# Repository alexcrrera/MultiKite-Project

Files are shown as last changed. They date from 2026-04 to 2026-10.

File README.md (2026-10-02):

# MULTIKITE PROJECT
Lausanne, Switzerland | 2026

Co-developed the take-off and landing mechanism for a multi-kite wind-energy prototype with another student.

Automated take-off and landing sequences using an Arduino-based controller and operator interface, replacing manual actuation with high-level commands to reduce operator intervention and support safer, repeatable operation.

<p align="center">
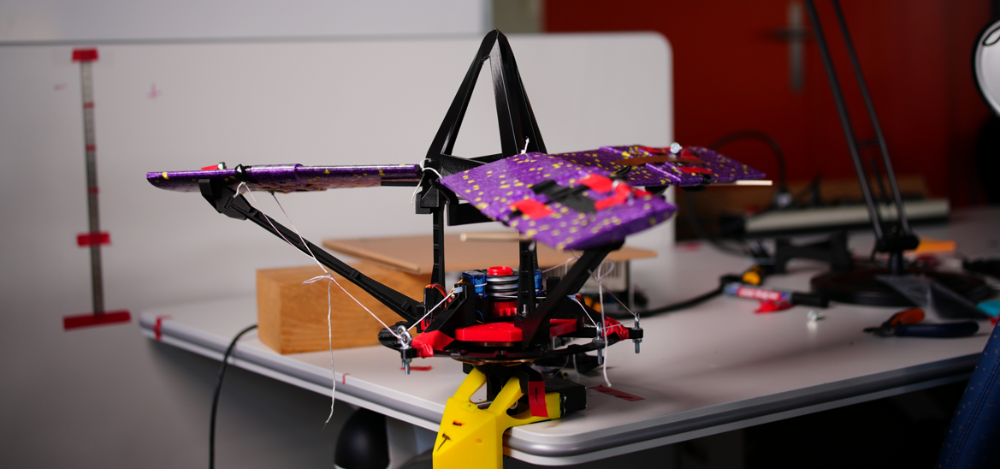
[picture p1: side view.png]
  
</p>

<p align="center">
  <i>Assembly</i>
</p>

<p align="center">
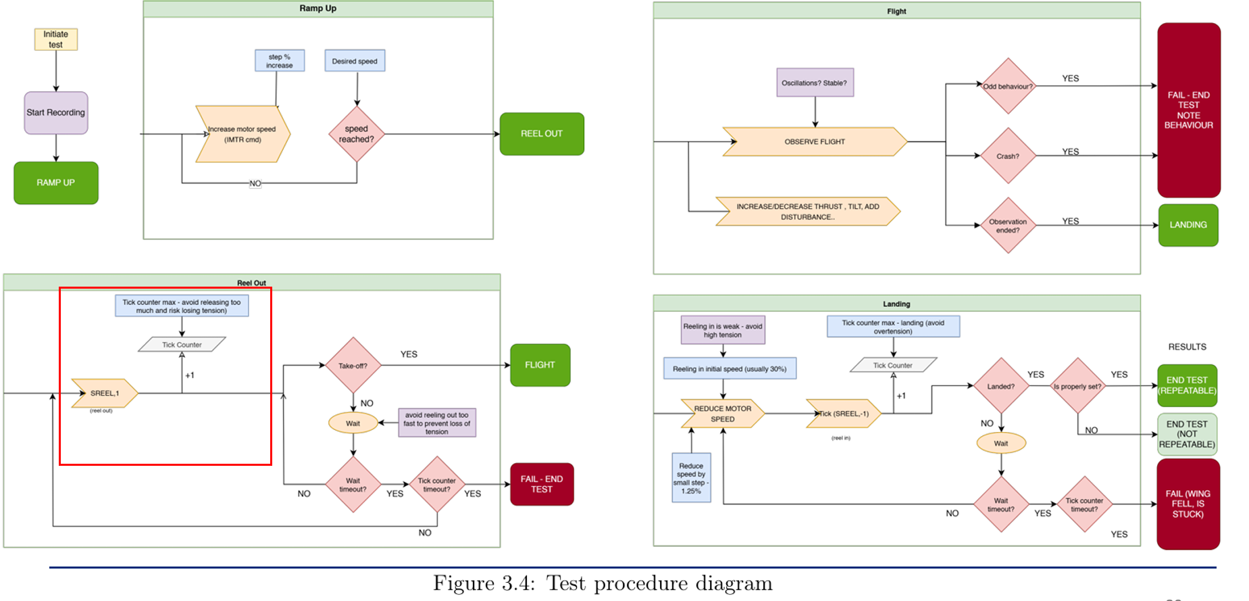
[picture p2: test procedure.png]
  
</p>

Ground station setup guide: how to upload the firmware to an Arduino Mega and connect it to Serial Studio for live telemetry and control.

The following is a detailed step-by-step tutorial for reproductability:

---

## Table of Contents

1. [Hardware Required](#1-hardware-required)
2. [Wiring](#2-wiring)
3. [Install Arduino IDE](#3-install-arduino-ide)
4. [Install Required Libraries](#4-install-required-libraries)
5. [Upload the Sketch](#5-upload-the-sketch)
6. [Install Serial Studio](#6-install-serial-studio)
7. [Configure and Connect Serial Studio](#7-configure-and-connect-serial-studio)
8. [Verify the Connection](#8-verify-the-connection)
9. [Command Reference](#9-command-reference)

---

## 1. Hardware Required

| Item | Notes |
|---|---|
| Arduino Mega 2560 | Any genuine or compatible board |
| Hobbywing ESC | Pulse range 850–1940 µs; other ESCs may need `b_systemParameters.ino` adjusted |
| Base tilt servo | Continuous rotation or position servo (see wiring note) |
| Reel servo | Continuous rotation servo |
| USB Type-B cable | USB-A to USB-B, used for programming and serial communication |
| External 5 V BEC or power supply | For servo power — do **not** power servos from the Arduino 5 V pin |

---

## 2. Wiring

The three actuators connect to PWM-capable pins on the Mega. All signal wires share a common ground with the Arduino.

```
                  Arduino Mega 2560
                 ┌─────────────────────┐
  Base Tilt ◄── │ Pin  9  (PWM / OC2B)│
  ESC       ◄── │ Pin 10  (PWM / OC2A)│
  Reel      ◄── │ Pin 11  (PWM / OC1A)│
                │                     │
  GND rail  ◄── │ GND                 │
  PC        ◄── │ USB (programming    │
                │      + telemetry)   │
                └─────────────────────┘
```

**Servo power**: connect signal and ground from the Arduino; power the servo rail from an external BEC. Never run servo power through the Arduino's 5 V regulator — stall current can exceed its rating and damage the board.

**Changing pin assignments**: edit `BASE_PIN`, `ESC_PIN`, and `REEL_PIN` in `b_systemParameters.ino`. Verify the replacement pins support hardware PWM on the Mega — not all digital pins do.

---

## 3. Install Arduino IDE

### Windows

1. Download Arduino IDE 2.x from [arduino.cc/en/software](https://www.arduino.cc/en/software).
2. Run the `.exe` installer and accept the defaults (includes USB drivers for the Mega).
3. Launch Arduino IDE.

### macOS

1. Download the `.dmg` from [arduino.cc/en/software](https://www.arduino.cc/en/software).
2. Open the disk image and drag **Arduino IDE** into **Applications**.
3. On first launch, macOS may prompt to install additional components — allow it.

### Linux (Ubuntu / Debian)

```bash
# Option A – AppImage (recommended, always up to date)
chmod +x arduino-ide_*.AppImage
./arduino-ide_*.AppImage

# Option B – apt (may install an older version)
sudo apt update && sudo apt install arduino
```

---

## 4. Install Required Libraries

The sketch depends on three libraries. Install them via **Tools → Manage Libraries…** in Arduino IDE.

| Library | Search term in Library Manager | Purpose |
|---|---|---|
| **TextParser** | `TextParser` (by Alex Taujenis) | Parses comma-separated incoming commands |
| **elapsedMillis** | `elapsedMillis` | Non-blocking millisecond/microsecond timers |
| **Servo** | Built-in — no install needed | PWM output to ESC and servos |

> **TextParser note**: if the Library Manager search returns no results, install manually:
> 1. Download from [arduinotextparser.readthedocs.io](https://arduinotextparser.readthedocs.io/en/latest/).
> 2. In Arduino IDE: **Sketch → Include Library → Add .ZIP Library…** and select the downloaded file.

---

## 5. Upload the Sketch

### 5.1 Select board and port

1. Connect the Arduino Mega to the computer via USB.
2. In Arduino IDE: **Tools → Board → Arduino AVR Boards → Arduino Mega or Mega 2560**.
3. **Tools → Processor → ATmega2560**.
4. **Tools → Port** — select the port that appeared when you plugged in the Mega:
   - **Windows**: `COMx` (e.g., `COM3`). If unsure: Device Manager → Ports (COM & LPT).
   - **macOS**: `/dev/cu.usbmodem` followed by a number.
   - **Linux**: `/dev/ttyACM0` or `/dev/ttyUSB0`. Run `ls /dev/tty*` before and after plugging in to find the new entry.

### 5.2 Open the sketch

**File → Open** → navigate to `src/mainCodeKite/mainCodeKite.ino`.

Arduino IDE loads all `.ino` files in the folder as tabs automatically. You should see tabs for `a_userParameters`, `b_systemParameters`, `c_parametersCheck`, `e_setupConfiguration`, `g_auxComputing`, `h_motorsUtilities`, `i_telemetryUtilities`, and `z_mainBody`.

### 5.3 Compile and upload

1. Click **Upload** (the right-arrow button) or press **Ctrl+U** (Cmd+U on macOS).
2. The IDE compiles then uploads. Watch the output panel at the bottom.
3. A successful upload ends with: `avrdude done. Thank you.`
4. Open **Tools → Serial Monitor**, set baud rate to **57600**. The board should print `STARTUP COMPLETE` within a second of resetting.

> **Compilation errors**: if the compiler rejects a value in `a_userParameters.ino`, the `static_assert` checks in `c_parametersCheck.ino` will display a descriptive error message. Fix the parameter and re-upload.

---

## 6. Install Serial Studio

Serial Studio is the ground station GUI used to display telemetry and send commands.
Download the latest release from: [github.com/Serial-Studio/Serial-Studio/releases](https://github.com/Serial-Studio/Serial-Studio/releases)

### Windows

1. Download the `.exe` installer.
2. Run it; default install location is fine.
3. Launch **Serial Studio** from the Start Menu.

### macOS

1. Download the `.dmg`.
2. Open it and drag **Serial Studio** to **Applications**.
3. First launch: right-click the app → **Open** to bypass Gatekeeper, then click **Open** in the dialog.

### Linux

1. Download the `.AppImage`.
2. Make it executable and run:
   ```bash
   chmod +x SerialStudio-*.AppImage
   ./SerialStudio-*.AppImage
   ```
3. If FUSE is missing: `sudo apt install libfuse2` then retry.

---

## 7. Configure and Connect Serial Studio

### 7.1 Load the project file

1. Launch Serial Studio.
2. **File → Open Project** (or drag-and-drop) → select:
   ```
   Base Station/base.json
   ```
   This loads the dashboard layout and all pre-configured action buttons.

### 7.2 Set connection parameters

In the left-side connection panel, configure:

| Parameter | Value | Reason |
|---|---|---|
| Port | Same port as in Arduino IDE | Whichever COM/tty the Mega is on |
| Baud Rate | **57600** | Must match `TELEM_BAUDRATE` in `a_userParameters.ino` |
| Data bits | 8 | Arduino default |
| Parity | None | Arduino default |
| Stop bits | 1 | Arduino default |
| Flow control | None | |

### 7.3 Connect

Click **Connect**. Serial Studio begins parsing frames and populates the dashboard.

The dashboard contains two panels:

| Panel | Contents |
|---|---|
| **STATUS** | Position (PX/PY/PZ), orientation (Yaw/Pitch/Roll), error message, acknowledgement message |
| **MOTOR STATUS** | Motor thrust bar, arm/disarm status, mode, brake status |

> Most STATUS fields (position, orientation) are currently commented out in the firmware and will show `--.-` until sensors are wired and those code sections are enabled.

---

## 8. Verify the Connection

After clicking Connect you should see:

- **ACK Message** field: `STARTUP COMPLETE` (sent once at boot), then `NO ERRORS` cycling at 10 Hz.
- **MOTOR STATUS**: `DISARMED`.
- **MOTOR THRUST**: `0` (bar at zero).

If all fields show `--.-`:
1. Confirm baud rate is `57600` on both the Arduino and Serial Studio.
2. Confirm the correct port is selected (not a Bluetooth COM port or another device).
3. Re-open the project JSON file in Serial Studio — the frame parser may need to reload.
4. Try pressing the Mega's reset button; it re-sends `STARTUP COMPLETE`.

---

## 9. Command Reference

These are the action buttons pre-configured in the Serial Studio project file. Buttons send commands over the same serial port used for telemetry.

| Button label | Command sent | Effect on firmware |
|---|---|---|
| ARM MOTOR | `MARM` | Sets `motor_armed = true` |
| DISARM MOTOR | `DSRM` | Sets `motor_armed = false` |
| MOTOR ON/OFF | `MTEST` | Toggles test mode — motor must be armed first |
| THR+ | `IMTR,2.5` | Adds 2.5 % to `motor_test_percentage` (clamped to `MOTOR_MAX_PERCENTAGE`) |
| THR- | `IMTR,-2.5` | Subtracts 2.5 % (clamped to `MOTOR_MIN_PERCENTAGE`) |
| THR+ FINE | `IMTR,1.25` | Adds 1.25 % |
| THR- FINE | `IMTR,-1.25` | Subtracts 1.25 % |
| TILT+ | `SBASE,1` | Starts one tilt-up burst (`BASE_TILT_BURST_TIME_MILLIS` ms) |
| TILT- | `SBASE,-1` | Starts one tilt-down burst |
| REEL IN | `SREEL,-1` | Reels in for one burst (`REEL_BURST_TIME_MILLIS` ms) |
| REEL OUT | `SREEL,1` | Reels out for one burst |

**Motor test procedure** (minimum safe sequence):

```
1. ARM MOTOR        → status changes to ARMED
2. MOTOR ON/OFF     → test mode starts, thrust at MOTOR_MIN_PERCENTAGE (8 %)
3. THR+             → increases by 2.5 % per press (THR+ FINE for 1.25 % steps)
4. MOTOR ON/OFF     → toggles test mode off, motor stops
5. DISARM MOTOR     → returns to safe DISARMED state
```

> For a detailed explanation of the firmware internals, parameter tuning, and how to extend the code, see [docs/CODE_INTERNALS.md](docs/CODE_INTERNALS.md).

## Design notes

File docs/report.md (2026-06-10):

# Automatic Take-Off/Landing Strategies and Control for a Multi-Kite Airborne Wind Energy System

## 1. Introduction

### 1.1 Airborne Wind Energy Systems

- Overview of Airborne Wind Energy (AWE).
- Motivation for replacing conventional wind turbines.
- Introduction to the MultiKite concept.
- Industrial constraints and scalability considerations.

### 1.2 Take-Off and Landing Challenge

- Importance of reliable take-off and landing (TOL) procedures.
- Existing desktop prototype and previous work.
- Limitations of the original high-speed spin-up approach.
- Need for a safer and more repeatable solution.

### 1.3 Objectives

The objectives of this project were:

- Develop a controlled take-off and landing strategy.
- Improve repeatability and operational robustness.
- Understand the critical parameters governing successful flight.
- Generate design recommendations for future prototypes.
- Contribute to the development of an automated TOL procedure.

---

# 2. System Description

### 2.1 Multi-Kite System Overview

- General operating principle.
- Flying wings.
- Cross-kite tether arrangement.
- Ground station and rotation mechanism.

### 2.2 Existing Prototype

- Description of the inherited system.
- Observed flight behavior.
- Previously used take-off procedure.

### 2.3 Design Requirements

Requirements identified at the start of the project:

- Repeatable take-off.
- Repeatable landing.
- Safety.
- Ease of testing.
- Compatibility with future automation.

---

# 3. Development of the Take-Off and Landing Structure

### 3.1 Initial Concepts

- Analysis of Version 0.
- Funnel-based guidance concept.
- Wing support philosophy.
- Preliminary experiments.

### 3.2 Mechanical Design

#### 3.2.1 Structural Extensions

- Radial extension.
- Vertical extension.
- Design rationale.

#### 3.2.2 Wing Support Mechanism

- Funnel geometry.
- Contact points.
- Attachment strategy.

#### 3.2.3 Arm Design

Design requirements:

- Low mass.
- High stiffness.
- Limited elongation.
- Ease of manufacturing.

Final design:

- Parametric geometry.
- Lightweight structure.
- Resistance to oscillatory loads.

### 3.3 Electronics and Software Integration

#### User Interface

- Real-time monitoring.
- Quick actions.
- Logging functionality.
- Safety features.

#### System Integration

- Ground station integration.
- Testing workflow.
- Repeatability improvements.

---

# 4. Experimental Methodology

### 4.1 Test Environment

- Test location.
- Experimental setup.
- Operating conditions.

### 4.2 Performance Metrics

Metrics used to evaluate performance:

- Successful take-off.
- Stable flight.
- Successful landing.
- Repeatability.
- Ease of operation.

### 4.3 Experimental Procedure

#### Pre-Flight Preparation

- Wing inspection.
- Mass balancing.
- Tether adjustment.
- Structural verification.

#### Take-Off Procedure

- Wing positioning.
- Initial rotation.
- Progressive reel-out.
- Transition to flight.

#### Landing Procedure

- Controlled reel-in.
- Wing capture.
- System shutdown.

---

# 5. Experimental Results

### 5.1 Iterative Development Process

The system was developed through successive iterations involving:

- Structural modifications.
- Wing balancing.
- Tether length adjustments.
- Attachment point optimization.

### 5.2 Successful Flight Campaign

#### Stable Take-Off

A controlled take-off procedure was successfully demonstrated by:

1. Holding the wings in a predefined configuration.
2. Initiating rotation.
3. Gradually reeling out the tethers.
4. Allowing aerodynamic forces to progressively establish flight.

#### Stable Flight

- Multiple successful flights were achieved.
- Flight was repeatable under the identified configuration.
- Stable rotational behavior was observed.

#### Landing

- Controlled landings were successfully demonstrated.
- The support structure enabled reliable wing capture.

### 5.3 Operational Procedure

A robust operational procedure was established, covering:

- Pre-flight preparation.
- Take-off sequence.
- Flight monitoring.
- Landing sequence.

This procedure significantly improved consistency compared to the previous direct spin-up method.

---

# 6. Sensitivity Analysis and Failure Investigation

### 6.1 Loss of Repeatability

Following a modification of the experimental setup, the previously successful configuration could not be recovered despite extensive measurements and reconstruction efforts.

### 6.2 Critical Parameters Identified

The experiments revealed strong sensitivity to:

- Wing mass distribution.
- Tether lengths.
- Tether attachment positions.
- Wing resting angle.
- Structural alignment.
- Contact conditions within the support structure.
- Small aerodynamic asymmetries.

### 6.3 Observed Failure Modes

Typical failure modes included:

- Failure to lift off.
- Asymmetric take-off.
- Excessive oscillations.
- Premature contact with the structure.
- Unstable flight behavior.

### 6.4 Lessons Learned

A major outcome of this work is the identification of the extreme sensitivity of the take-off phase.

Small variations in geometry or mass distribution can significantly affect system behavior and determine whether take-off succeeds or fails.

This finding highlights the need for:

- Tight manufacturing tolerances.
- Precise assembly procedures.
- Calibration methodologies.
- Improved robustness in future designs.

---

# 7. Discussion

### 7.1 Advantages of the Proposed Approach

Compared to the previous high-speed spin-up method:

- Lower required rotational speeds.
- Improved control during take-off.
- Cleaner landing procedure.
- Better suitability for automation.

### 7.2 Current Limitations

The developed structure presents several drawbacks:

#### Radial Structural Extension

- Increased inertia.
- Increased hazard during operation.

#### Vertical Structural Extension

- Additional mass.
- Increased overall dimensions.

#### General Limitations

- Large footprint.
- Complex assembly.
- Strong parameter sensitivity.

### 7.3 Implications for Future Systems

The results suggest that future designs should prioritize:

- Mechanical simplicity.
- Reduced sensitivity.
- Automated calibration.
- Reduced structural mass.

---

# 8. Next-Generation Take-Off Structure

### 8.1 Motivation

The current structure successfully demonstrated the concept but remains too large and complex for future development.

### 8.2 Proposed Concept

Potential improvements include:

- Retractable support arms.
- Hook-based retention mechanism.
- Passive deployment through centrifugal force.
- Integrated damping mechanisms.

### 8.3 Expected Benefits

Compared to the current version:

- Reduced mass.
- Reduced inertia.
- Smaller storage volume.
- Lower aerodynamic interference.
- Simplified operation.

### 8.4 Future Work

Future efforts should focus on:

- Validation of the new concept.
- Reduction of parameter sensitivity.
- Development of automatic take-off procedures.
- Development of automatic landing procedures.
- Integration with flight control systems.

---

# 9. Conclusion

This project investigated alternative take-off and landing strategies for a MultiKite Airborne Wind Energy system.

A dedicated support structure was designed, constructed, and experimentally validated. Using this structure, repeatable take-off, stable flight, and controlled landing were successfully demonstrated.

The experimental campaign revealed that the system is highly sensitive to small geometric and mass-property variations. While this sensitivity ultimately prevented recovery of the original successful configuration after modifications, it provided valuable insight into the dominant factors governing take-off behavior.

The limitations identified in the current architecture motivated the development of a next-generation concept aimed at reducing mass, inertia, complexity, and sensitivity while improving suitability for future automation.

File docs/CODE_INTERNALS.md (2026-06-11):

# MultiKite Firmware Internals

Reference for anyone modifying the Arduino sketch. Assumes familiarity with embedded C++, PWM, and serial protocols. Does not re-explain Arduino basics.

---

## Table of Contents

1. [File Structure](#1-file-structure)
2. [Execution Flow](#2-execution-flow)
3. [Serial Protocol](#3-serial-protocol)
   - [Outgoing telemetry](#31-outgoing-telemetry)
   - [Incoming commands](#32-incoming-commands)
4. [Actuator Subsystems](#4-actuator-subsystems)
   - [ESC / Motor](#41-esc--motor-pin-10)
   - [Reel Servo](#42-reel-servo-pin-11)
   - [Base Tilt Servo](#43-base-tilt-servo-pin-9)
   - [Burst timing logic](#44-burst-timing-logic)
5. [Motor State Machine](#5-motor-state-machine)
6. [Parameter Reference](#6-parameter-reference)
7. [How to Extend](#7-how-to-extend)
   - [Add a telemetry field](#71-add-a-telemetry-field)
   - [Add an incoming command](#72-add-an-incoming-command)
   - [Adjust timing and speed](#73-adjust-timing-and-speed)
8. [Known Issues and Discrepancies](#8-known-issues-and-discrepancies)

---

## 1. File Structure

Arduino compiles all `.ino` files in the sketch folder into a single translation unit, concatenated alphabetically by filename. The naming convention (`a_`, `b_`, ..., `z_`) enforces a deliberate include order.

| File | Compile order | Role |
|---|---|---|
| `mainCodeKite.ino` | 1 (main tab) | Comment header only; no code |
| `a_userParameters.ino` | 2 | All user-tunable `constexpr` values — **the only file end-users should edit** |
| `b_systemParameters.ino` | 3 | Hardware pin assignments, object declarations, runtime state variables, pulse ranges — do not modify unless changing hardware |
| `c_parametersCheck.ino` | 4 | `static_assert` guards that reject invalid parameter combinations at compile time |
| `e_setupConfiguration.ino` | 5 | `initSystem()`, `initServos()`, `initTelem()` called once from `setup()` |
| `g_auxComputing.ino` | 6 | State validation (`checkStateSystem()`), EWA filter, utility math |
| `h_motorsUtilities.ino` | 7 | Periodic handlers (`handleMotor()` etc.) and low-level PWM write functions |
| `i_telemetryUtilities.ino` | 8 | Serial read/write, frame parser, command dispatch (`processTelem()`) |
| `z_mainBody.ino` | 9 (last) | `setup()` and `loop()` entry points |

> `z_mainBody.ino` is last so all declarations in earlier files are visible. Do not move `setup()`/`loop()` to another file.

---

## 2. Execution Flow

`setup()` runs once; `loop()` runs continuously.

```mermaid
flowchart TD
    A([Power on / Reset]) --> B[setup]
    B --> B1["Serial.begin(57600)"]
    B1 --> B2[initSystem]
    B2 --> B3["initTelem() → TELEM.begin(TELEM_BAUDRATE)"]
    B2 --> B4["initServos() → attach + arm ESC + set stop pulses"]
    B2 --> B5["sendMessage('STARTUP COMPLETE')"]
    B5 --> L([loop])

    L --> C[checkStateSystem]
    C --> D[handleTelemetry]
    D --> D1{"micros() interval\n= 1e6 / TELEMETRY_FREQUENCY"}
    D1 -->|elapsed| D2[sendTelem]
    D1 -->|not yet| D3[readTelem / processTelem]
    D2 --> D3

    D3 --> E[handleReelServo]
    E --> E1{"millis() interval\n= 1000 / REEL_SERVO_FREQUENCY"}
    E1 -->|elapsed| E2[reelServoWrite]
    E1 -->|not yet| F[handleMotor]
    E2 --> F

    F --> F1{"millis() interval\n= 1000 / MOTOR_FREQUENCY"}
    F1 -->|elapsed| F2[motorWrite]
    F1 -->|not yet| G[handleBaseTiltServo]
    F2 --> G

    G --> G1{"millis() interval\n= 1000 / BASE_TILT_SERVO_FREQUENCY"}
    G1 -->|elapsed| G2[baseTiltServoWrite]
    G1 -->|not yet| L
    G2 --> L
```

**Timing model**: all scheduling uses software polling (`millis()`/`micros()` deltas stored in `static` local variables). There are no hardware interrupts or RTOS tasks. The loop is cooperative; a blocking call in any handler will delay all others. Keep all handlers fast — no `delay()` after `setup()`.

---

## 3. Serial Protocol

A single hardware `Serial` port (USB) carries both outgoing telemetry and incoming commands, bidirectionally, at the same baud rate.

### 3.1 Outgoing Telemetry

**Direction**: Arduino → PC (Serial Studio)  
**Rate**: `TELEMETRY_FREQUENCY` Hz (default 10 Hz)  
**Framing**: newline before, `*` after each packet

```
\n$MKTE,f1,f2,f3,...,f27*
```

`sendTelem()` builds a `String fields[28]` array and serialises it. Fields not assigned default to an empty string, appearing as empty between consecutive commas.

**Active field map** (indices that currently carry data):

| Index | Variable | Type | Example value |
|---|---|---|---|
| 0 | Frame header | literal | `$MKTE` |
| 10 | `motor_output_percentage` | float | `23.5` |
| 11 | `motor_on` | string | `ON` / `OFF` |
| 12 | `motor_armed` | string | `ARMED` / `DISARMED` |
| 17 | Flight mode | string | `TEST MODE` / `STANDBY` |
| 25 | `errorMessage` | string | `NO ERRORS` |
| 26 | `returnMessage` | string | `MOTOR ARMED` |
| 27 | Fixed checksum stub | literal | `12` |

All other indices (1–9, 13–16, 18–24) are reserved for future sensors (IMU, GPS, SD card status) and are commented out in `i_telemetryUtilities.ino`.

**Example packet** (most fields empty):

```
\n$MKTE,,,,,,,,,,,23.50,ON,ARMED,,,,, STANDBY,,,,,,,,,,NO ERRORS,MOTOR ARMED,12*
```

**Adding more fields**: see [§7.1](#71-add-a-telemetry-field).

---

### 3.2 Incoming Commands

**Direction**: PC (Serial Studio) → Arduino  
**Framing**: newline-terminated (`\n` is the end-of-line delimiter in Serial Studio actions)

`readTelem()` reads one character at a time into a 50-byte circular buffer (`incomingDataTelem`). On receiving `\n`, it copies the buffer to `incomingDataTelemString` and calls `processTelem()`.

`processTelem()` calls `checkHeaderTelem()` first, which does substring matching (`indexOf`) against known command strings and sets a `TelemIdentity` integer used in the `switch` dispatch.

```mermaid
flowchart TD
    A[character received on TELEM] --> B{char == newline?}
    B -->|yes| C[copy buffer to incomingDataTelemString]
    B -->|no| D{buffer overflow?\nindex >= 49}
    D -->|yes| E[reset index and string]
    D -->|no| F[append char, increment index]
    C --> G[processTelem]
    G --> H[checkHeaderTelem]
    H --> I{TelemIdentity}
    I -->|-1 no match| Z[return]
    I -->|14 IMTR| J["commaParser.parseLine → adjust motor_test_percentage"]
    I -->|15 SBASE| K[set base_tilt_down or base_tilt_up + record burst start]
    I -->|16 SREEL| L[set reel_in or reel_out + record burst start]
```

**Command table**:

| Keyword detected | `TelemIdentity` | Expected format | Action |
|---|---|---|---|
| `MARM` | (direct) | `MARM` | `motor_armed = true` |
| `DSRM` | (direct) | `DSRM` | `motor_armed = false` |
| `MOFF` | (direct) | `MOFF` | `motor_on = false` |
| `MTEST` | (direct) | `MTEST` | `toggleTest()` |
| `IMTR` | 14 | `IMTR,<float>` | `motor_test_percentage += inter`, clamped |
| `SBASE` | 15 | `SBASE,<-1\|1>` | Sets tilt direction flag + burst timer |
| `SREEL` | 16 | `SREEL,<-1\|1>` | Sets reel direction flag + burst timer |
| `TAO` | (direct) | `TAO` | Placeholder; sets `returnMessage` only |
| `LND` | (direct) | `LND` | Placeholder; sets `returnMessage` only |

**`checkHeaderTelem` evaluation order**: commands are checked via sequential `if` blocks, not `else if`. Multiple keywords in the same packet will all match. In practice Serial Studio sends one command per button press, so this is not a concern. Be aware when sending raw commands manually.

**`commaParser`** (TextParser library) is used only for the two-field commands (`IMTR`, `SBASE`, `SREEL`). It parses `COMMAND,VALUE` and returns the float value in `inter`.

---

## 4. Actuator Subsystems

All three actuators are controlled via the Arduino `Servo` library which outputs 50 Hz PWM with microsecond-precision pulse width. The ESC interprets this signal identically to a standard RC receiver.

### 4.1 ESC / Motor (Pin 10)

| Parameter | Value | Source |
|---|---|---|
| Pulse range | 850–1940 µs | Hobbywing datasheet |
| Update rate | 50 Hz (20 ms) | `MOTOR_FREQUENCY` |
| 0 % → pulse | 850 µs | `ESC_LOW_PULSE` |
| 100 % → pulse | 1940 µs | `ESC_HIGH_PULSE` |
| Max user-settable | 50 % → ~1395 µs | `MOTOR_MAX_PERCENTAGE` |
| Min user-settable | 8 % → ~941 µs | `MOTOR_MIN_PERCENTAGE` |

`motorWrite()` maps `motor_output_percentage` linearly onto the pulse range using `map()`. If `motor_on` or `motor_armed` is false, `motor_output_percentage` is forced to 0 and the ESC receives `ESC_LOW_PULSE` (idle/brake signal).

**ESC arming sequence**: `initServos()` writes `ESC_LOW_PULSE` and calls `delay(1000)` — this 1-second low pulse at startup is required by most ESCs to complete their arming handshake. Do not remove this delay.

---

### 4.2 Reel Servo (Pin 11)

The reel servo is a continuous rotation servo commanded by pulse width. The midpoint pulse (`REEL_STOP_PULSE = 1500 µs`) means stopped. Pulses above stop spin in one direction; pulses below spin in the other.

| Parameter | Value |
|---|---|
| Pulse range | 1000–2000 µs |
| Stop pulse | 1500 µs (midpoint) |
| Update rate | 50 Hz |
| Reel-in speed | `REEL_STOP_PULSE × (1 − REEL_SPEED_DELTA_PERCENTAGE_REEL_IN)` |
| Reel-out speed | `REEL_STOP_PULSE × (1 + REEL_SPEED_DELTA_PERCENTAGE_REEL_OUT)` |
| Burst duration | `REEL_BURST_TIME_MILLIS` ms |

Speed is controlled by a fractional offset from the stop pulse. `REEL_SPEED_DELTA_PERCENTAGE_REEL_IN = 0.08` means reel-in pulse = `1500 × 0.92 = 1380 µs`.

---

### 4.3 Base Tilt Servo (Pin 9)

Identical architecture to the reel servo. The pulse range is asymmetric (1000–1940 µs), so the stop pulse is slightly off-centre:

```
BASE_TILT_STOP_PULSE = round((1000 + 1940) / 2.0) = 1470 µs
```

Speed offsets are applied relative to `BASE_TILT_STOP_PULSE`:

```
tilt-down pulse = STOP + DELTA_POSITIVE × (HIGH − STOP)
                = 1470 + 0.2 × (1940 − 1470)
                = 1470 + 94 = 1564 µs

tilt-up pulse   = STOP − DELTA_NEGATIVE × (STOP − LOW)
                = 1470 − 0.2 × (1470 − 1000)
                = 1470 − 94 = 1376 µs
```

The naming convention ("positive tilt" = `base_tilt_down`) follows the mechanical geometry of the specific platform; verify direction on your hardware before flying.

---

### 4.4 Burst Timing Logic

Reel and base tilt both use a burst model: a single command fires the servo for a fixed duration, then it returns to stop automatically. This prevents runaway actuation from dropped commands.

```mermaid
flowchart TD
    A[SREEL or SBASE command received] --> B[set direction flag = true\nrecord burst_start_time = millis]
    B --> C([next handleXServo tick])
    C --> D{"millis() − burst_start_time\n>= BURST_TIME?"}
    D -->|no| E["write direction pulse\n(reel-in / reel-out / tilt-up / tilt-down)"]
    E --> C
    D -->|yes| F[reset direction flags to false\nburst_start_time = 0]
    F --> G[write STOP_PULSE]
    G --> C
```

**Key consequence**: the "STOP TILTING" button (`SBASE,0`) sends a value of 0, which falls through the `processTelem()` switch without matching any case. The servo does **not** stop early — it always runs the full burst duration. If you need a genuine early-abort command, add an explicit `inter == 0` branch that clears the direction flags.

---

## 5. Motor State Machine

Three boolean variables drive motor behaviour: `motor_armed`, `motor_on`, `motor_test_mode`.

```mermaid
stateDiagram-v2
    [*] --> Idle : power-on default

    Idle --> Armed : MARM
    Armed --> Idle : DSRM or MOFF

    Armed --> TestMode : MTEST\n(sets motor_on = true\nmotor_test_percentage = MIN)
    TestMode --> TestMode : IMTR,±x\n(adjusts test_percentage, clamped MIN..MAX)
    TestMode --> Idle : second MTEST\nor MOFF or DSRM

    note right of Idle
        motor_armed = false
        motor_on    = false
        motor output = 0
    end note

    note right of Armed
        motor_armed = true
        motor_on    = false
        motor output = 0
    end note

    note right of TestMode
        motor_armed = true
        motor_on    = true
        motor_test_mode = true
        motor output = test_percentage
    end note
```

`checkStateSystem()` runs each loop iteration as a guard: if `motor_test_mode` is active but the motor becomes unarmed or turned off (e.g., via a concurrent `DSRM`), it cleans up `motor_test_mode` and resets the test percentage to `MOTOR_MIN_PERCENTAGE`.

Normal (non-test) flight with `motor_on = true` and `motor_test_mode = false` is structurally possible but has no current command to set it. `motor_output_percentage` would need to be driven externally (e.g., from a future autonomous controller).

---

## 6. Parameter Reference

All values in `a_userParameters.ino`. `c_parametersCheck.ino` enforces the bounds listed here at compile time.

| Constant | Default | Unit | Min | Max | Effect |
|---|---|---|-----|-----|---|
| `TELEMETRY_FREQUENCY` | 10 | Hz | 1 | 100 | Outgoing packet rate. Scale baud rate proportionally if increased significantly. |
| `TELEM_BAUDRATE` | 57600 | bps | — | — | Must match Serial Studio. Whitelist: 9600, 14400, 19200, 28800, 38400, 57600, 115200, 230400, 250000, 460800, 921600. |
| `MOTOR_MAX_PERCENTAGE` | 50.0 | % | > MIN | 100 | Hard ceiling on thrust commands. |
| `MOTOR_MIN_PERCENTAGE` | 8.0 | % | 0 | < MAX | Lowest commandable thrust (below this the motor typically cannot spin from rest). |
| `REEL_SPEED_DELTA_PERCENTAGE_REEL_IN` | 0.08 | fraction | > 0 | ≤ 0.20 | Speed as fraction of stop-pulse range. Higher = faster reel-in. |
| `REEL_SPEED_DELTA_PERCENTAGE_REEL_OUT` | 0.06 | fraction | > 0 | ≤ 0.20 | Same for reel-out. |
| `REEL_BURST_TIME_MILLIS` | 300 | ms | > 0 | < 500 | Duration of one SREEL command. |
| `BASE_TILT_SPEED_DELTA_PERCENTAGE_POSITIVE_TILT` | 0.2 | fraction | > 0 | ≤ 0.30 | Fraction of half-range added to stop pulse for tilt-down. |
| `BASE_TILT_SPEED_DELTA_PERCENTAGE_NEGATIVE_TILT` | 0.2 | fraction | > 0 | ≤ 0.30 | Fraction subtracted for tilt-up. |
| `BASE_TILT_BURST_TIME_MILLIS` | 400 | ms | > 0 | < 500 | Duration of one SBASE command. |

**System constants** (in `b_systemParameters.ino`, change only with hardware changes):

| Constant | Value | Notes |
|---|---|---|
| `BASE_PIN` | 9 | Must be a PWM pin |
| `ESC_PIN` | 10 | Must be a PWM pin |
| `REEL_PIN` | 11 | Must be a PWM pin |
| `ESC_LOW_PULSE` | 850 µs | Hobbywing minimum — verify against your ESC datasheet |
| `ESC_HIGH_PULSE` | 1940 µs | Hobbywing maximum |
| `BASE_TILT_LOW_PULSE` | 1000 µs | |
| `BASE_TILT_HIGH_PULSE` | 1940 µs | |
| `REEL_LOW_PULSE` | 1000 µs | |
| `REEL_HIGH_PULSE` | 2000 µs | |
| `bufferSize` | 50 | Max incoming packet length in bytes |

---

## 7. How to Extend

### 7.1 Add a telemetry field

1. **Pick an unused index** (0–27) in `sendTelem()`. Indices 1–9, 13–16, 18–24 are currently empty. Avoid index 0 (header) and 27 (checksum stub).

2. **Assign the value** in `sendTelem()`:
   ```cpp
   fields[18] = String(yourVariable, 2); // 2 decimal places
   ```

3. **Add the field in Serial Studio**:
   - Open `Base Station/base.json` in a text editor.
   - In the appropriate `"groups"` → `"datasets"` array, add a new entry:
   ```json
   {
       "index": 18,
       "title": "MY SENSOR",
       "units": "m/s",
       "widget": "",
       "graph": false
   }
   ```
   - Reload the project file in Serial Studio.

4. **Increase `NUM_FIELDS`** if you need more than 28 fields (unlikely without hardware expansion).

> **Index alignment**: the `index` value in the JSON maps directly to the position in the comma-split array, where index 0 is `$MKTE`. There is no offset.

---

### 7.2 Add an incoming command

1. **Choose a unique keyword** (no spaces, no commas). Check that it does not appear as a substring of an existing keyword — `checkHeaderTelem` uses `indexOf`, not exact match.

2. **Detect the keyword** in `checkHeaderTelem()`:
   ```cpp
   if (incomingDataTelemString.indexOf("MYCMD") != -1) {
       TelemIdentity = 20; // pick an unused case number
   }
   ```

3. **Handle the command** in `processTelem()`:
   ```cpp
   case 20:
       // for a simple flag command, no parsing needed:
       myFlag = true;
       returnMessage = "MY CMD RECEIVED";
       break;

   // or, for a parameterised command:
   case 20:
       commaParser.parseLine(incomingDataTelem, headerTelem, inter);
       myValue = constrain(inter, 0.0f, 100.0f);
       returnMessage = "MY VALUE: " + String(myValue);
       break;
   ```

4. **Add a Serial Studio action button** in the JSON `"actions"` array:
   ```json
   {
       "title": "My Command",
       "txData": "MYCMD,42",
       "eol": "\n",
       "icon": "Services"
   }
   ```

---

### 7.3 Adjust timing and speed

**Increase telemetry rate**: raise `TELEMETRY_FREQUENCY` in `a_userParameters.ino`. At 10 Hz with the current 28-field packet (roughly 150 characters), 57600 baud has headroom. At 50 Hz consider raising `TELEM_BAUDRATE` to 115200 and updating Serial Studio accordingly.

**Change servo update rate**: `REEL_SERVO_FREQUENCY`, `BASE_TILT_SERVO_FREQUENCY`, `MOTOR_FREQUENCY` are all in `b_systemParameters.ino`. Standard servos and ESCs expect 50 Hz; digital servos typically accept up to 330 Hz. Changing these values beyond what the hardware supports may cause erratic behaviour.

**Longer burst steps**: increase `REEL_BURST_TIME_MILLIS` or `BASE_TILT_BURST_TIME_MILLIS`. The `static_assert` clamps both to < 500 ms. To allow longer bursts, raise `REEL_BURST_TIME_MILLIS_CLAMPING` or `BASE_BURST_TIME_MILLIS_CLAMPING` in `b_systemParameters.ino` simultaneously.

---

## 8. Known Issues and Discrepancies

### 8.1 Serial Studio JSON vs firmware field indices

The JSON file in `Base Station/` was authored for an earlier field layout. Several mappings are incorrect with the current firmware:

| JSON label | JSON index | Current firmware field at that index | Correct index for this label |
|---|---|---|---|
| MOTOR THRUST (bar) | 11 | `motor_on` → `"ON"/"OFF"` string | Should be 10 (`motor_output_percentage`) |
| MODE | 18 | empty (unassigned) | Should be 17 (`TEST MODE`/`STANDBY`) |
| ERROR MESSAGE | 26 | `returnMessage` (the ACK) | Should be 25 (`errorMessage`) |
| ACK Message | 27 | fixed `"12"` | Should be 26 (`returnMessage`) |

**Impact**: the motor thrust bar will not animate; the MODE field will show nothing; error and ACK messages are swapped. Fix by editing the `index` values in the JSON or by re-assigning the `fields[]` slots in `sendTelem()`.

---

### 8.2 Double `Serial.begin()` on startup

`z_mainBody.ino` calls `Serial.begin(57600)` directly in `setup()`, then `initSystem()` calls `initTelem()` which calls `TELEM.begin(TELEM_BAUDRATE)`. Since `TELEM` is defined as `Serial`, the port is initialised twice. Arduino handles this gracefully (the second call re-initialises with the same rate), but the hardcoded `57600` in `z_mainBody.ino` will not pick up a changed `TELEM_BAUDRATE` from `a_userParameters.ino`. Remove the raw `Serial.begin(57600)` line from `z_mainBody.ino` to ensure only `initTelem()` controls the baud rate.

---

### 8.3 `SBASE,0` stop command is a no-op

The `processTelem()` case 15 handles values `-1` and `1` only. `SBASE,0` is ignored; the "STOP TILTING" button in Serial Studio has no effect. The servo stops naturally when the burst timer expires. To implement a genuine abort, add `else if (inter == 0) { base_tilt_down = false; base_tilt_up = false; }` in case 15.

---

### 8.4 Reel speed formula inconsistency

The reel-in and reel-out pulses are calculated differently from the base tilt servo:

```cpp
// Reel: multiplicative offset from STOP
reel_in:  REEL_STOP_PULSE * (1 - DELTA_IN)
reel_out: REEL_STOP_PULSE * (1 + DELTA_OUT)

// Base tilt: additive offset scaled to half-range
tilt-down: STOP + DELTA × (HIGH - STOP)
tilt-up:   STOP - DELTA × (STOP - LOW)
```

The reel formula makes the speed delta asymmetric because `REEL_STOP_PULSE` differs from the midpoint of the range only when the range is not centred on 1500 µs (currently it is: `(1000+2000)/2 = 1500`). For the reel servo this produces equivalent results. For a servo with an asymmetric range, use the base-tilt formula instead.

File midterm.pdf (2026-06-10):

# Automatic take-off/landing strategies and control for a multi-kite Airborne Wind Energy system

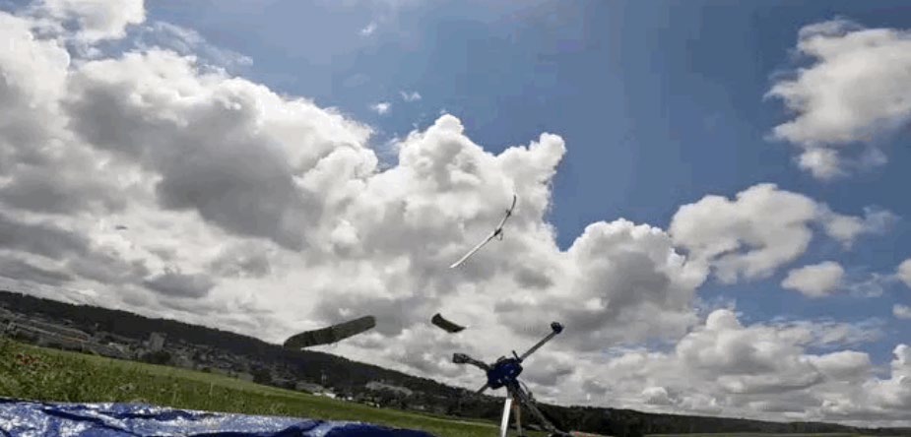
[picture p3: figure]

Alex CARRERA | M1 MT
Midterm Presentation

https://site.alphanemo.com/

Supervision: J. Waibel, Prof. C. Jones

# Context and introduction

https://site.alphanemo.com/

## - Continuation of the work of the AlphAnemo Team - Develop MultiKite Energy Systems - Industrial constraints

# Context and introduction

https://pngtree.com/freepng/png-wind-turbines_14597478.html
- Large structure
- Large cost
- Large footprint (visual)
- Height limits force placement in highly visible areas https://site.alphanemo.com/

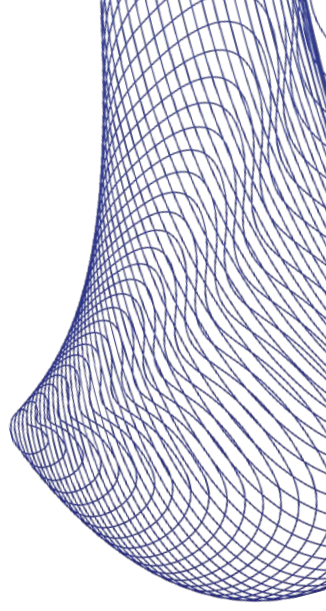
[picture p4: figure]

# Context and introduction

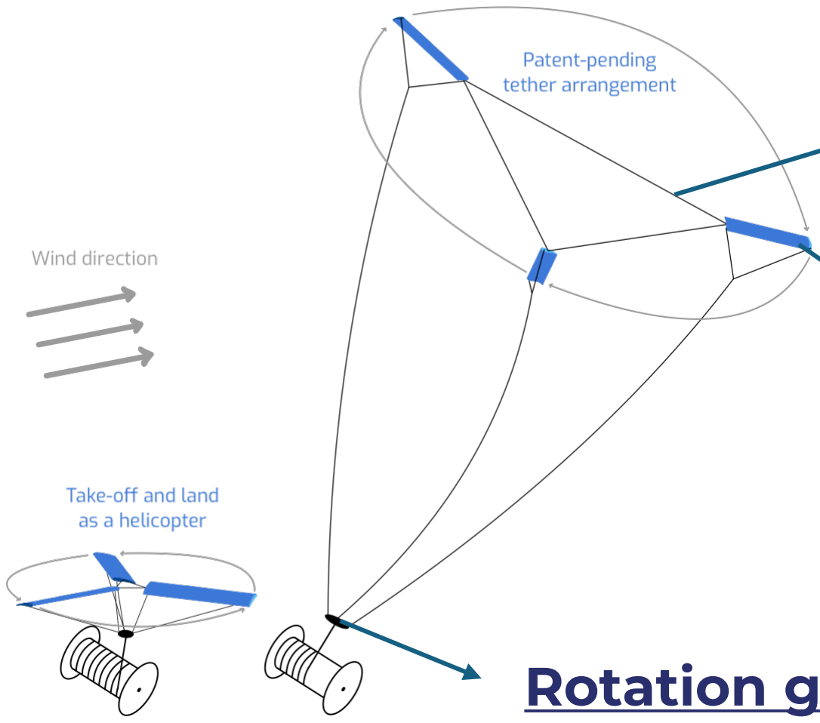
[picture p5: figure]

https://site.alphanemo.com/

Cross-Kite tethers

Rotation generates energy (dynamo)

Flying wings

# Context and introduction

## - Continuation of the work of the AlphAnemo Team

https://site.alphanemo.com/

## - Develop MultiKite Energy Systems - Industrial constraints - Work in pseudo-parallel with another student

# Context and introduction

https://www.linkedin.com/company/alphanemo/post

## - Continuation of the work of the AlphAnemo Team

# Context and introduction

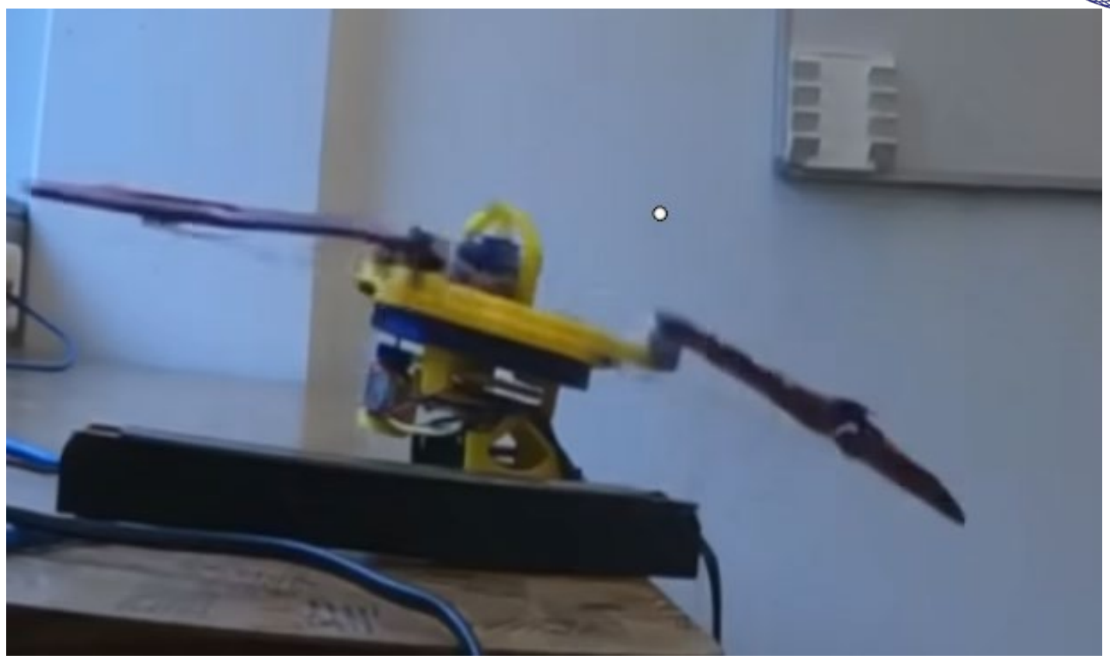
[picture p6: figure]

https://www.linkedin.com/company/alphanemo/post

## - Continuation of the work of the AlphAnemo Team

”chaotic take-off and landing”

# Summary

:

- Context and Introduction Goals First Major Version | Construction | Integration | Testings and results | Limitations and shortcomings Future work and conclusion

# Goals

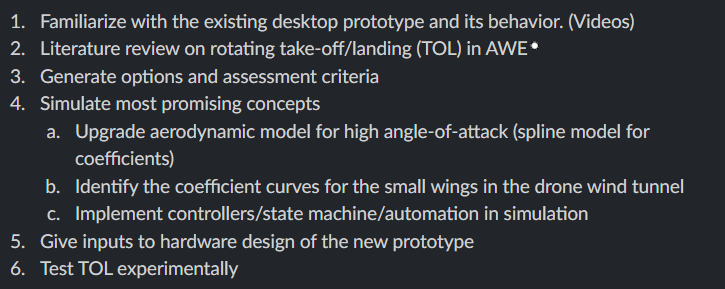
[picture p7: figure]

# Goals

Understand wing configuration

# Goals

# Goals

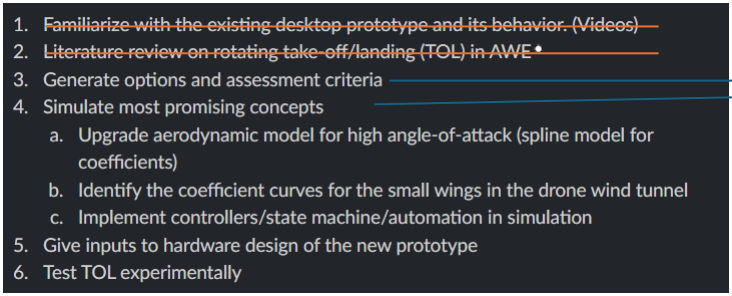
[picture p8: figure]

Version 0 created

# Version 0

funnels

Tether attachement point

30º AOA

# Goals

# Goals

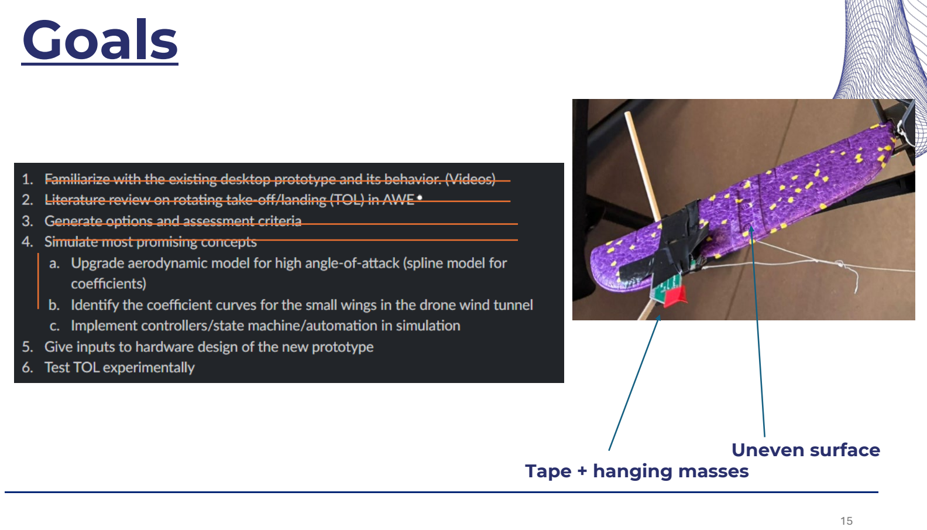
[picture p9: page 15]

Tape + hanging masses

Uneven surface

# Goals

high uncertainty

standby

# Goals

Direct involvement

Current phase (version 1)

# Version 1: Construction and integration

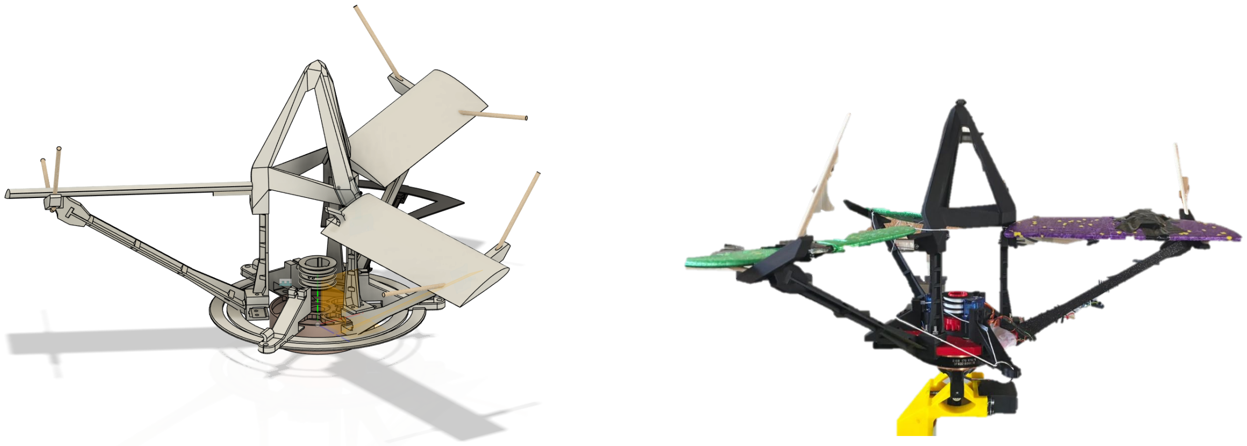
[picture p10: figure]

Projet Image | 18

> Based on Version 0

# Version 1: Construction and integration

Projet Image | 19

> Based on Version 0

# Version 1: Construction and integration

Projet Image | 20

> Based on Version 0

Old desktop prototype | Radial structural extension

Wings supported

Vertical structural extension

# Version 1: Construction and integration

Projet Image | 21

> Based on Version 0

funnel | Contact point

# Version 1: Construction and integration

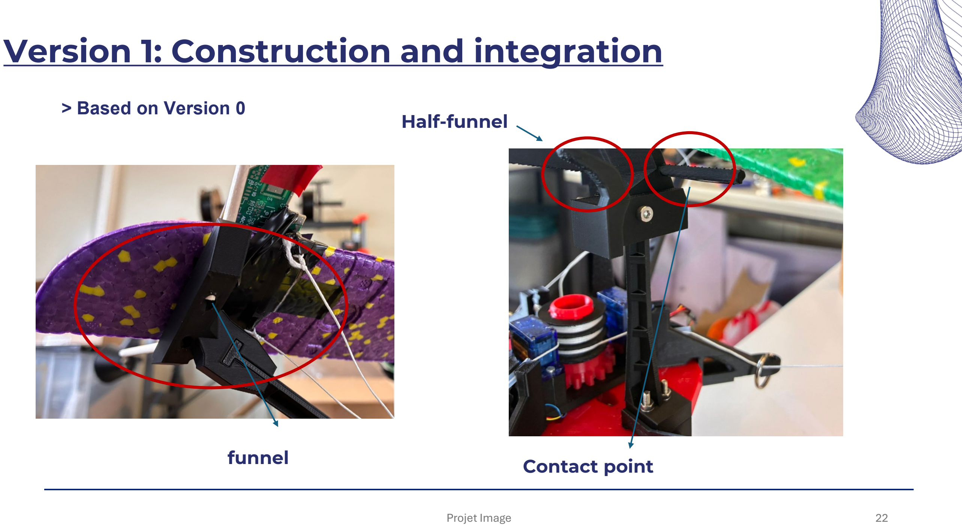
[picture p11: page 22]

Projet Image | 22

> Based on Version 0

funnel | Contact point

Half-funnel

# Version 1: Construction and integration

Projet Image | 23

> Based on Version 0

Contact point

Half-funnel

# Version 1: Construction and integration

Projet Image | 24

> Based on Version 0

“pyramid”

# Version 1: Construction and integration

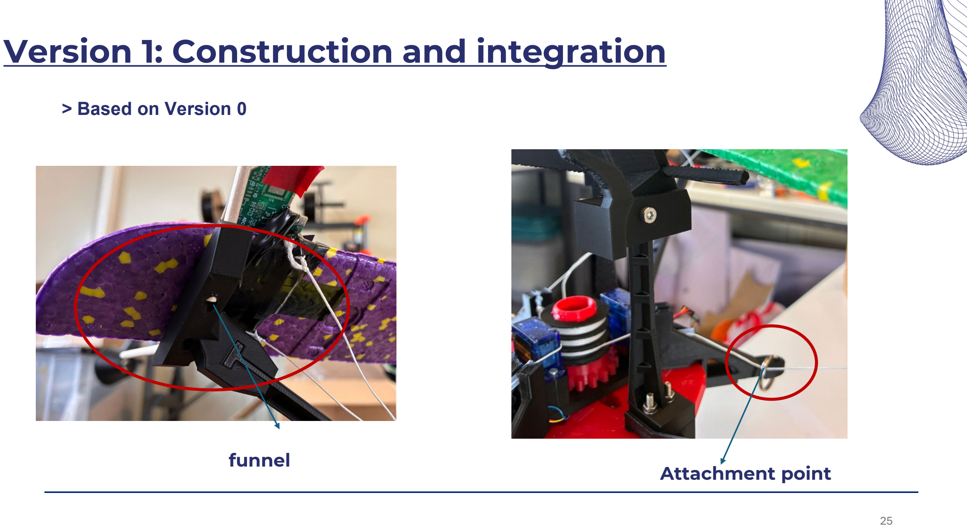
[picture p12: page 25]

> Based on Version 0

funnel | Attachment point

# Version 1

Based on Version 0

Arms:
- Weight requirement
- Strength requirement
- Elongation requirement

# Version 1

Based on Version 0

Arms:
- Weight requirement
- Strength requirement
- Elongation requirement
- > T-shape

# Version 1

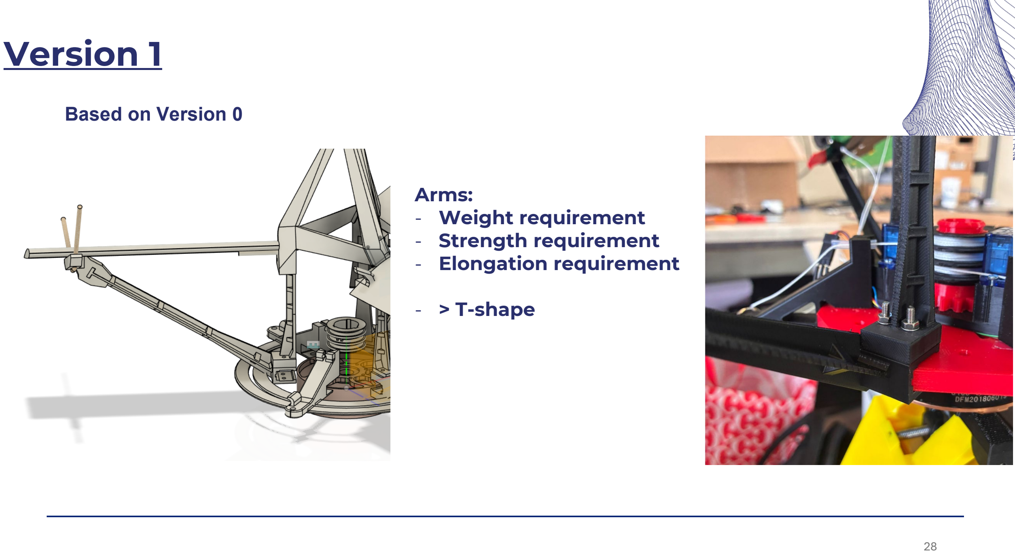
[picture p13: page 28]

Based on Version 0

Arms:
- Weight requirement
- Strength requirement
- Elongation requirement
- > T-shape

# Version 1

Based on Version 0

Arms:
- Weight requirement
- Strength requirement
- Elongation requirement
- > T-shape

# Version 1

Based on Version 0

Arms:
- Weight requirement
- Strength requirement
- Elongation requirement

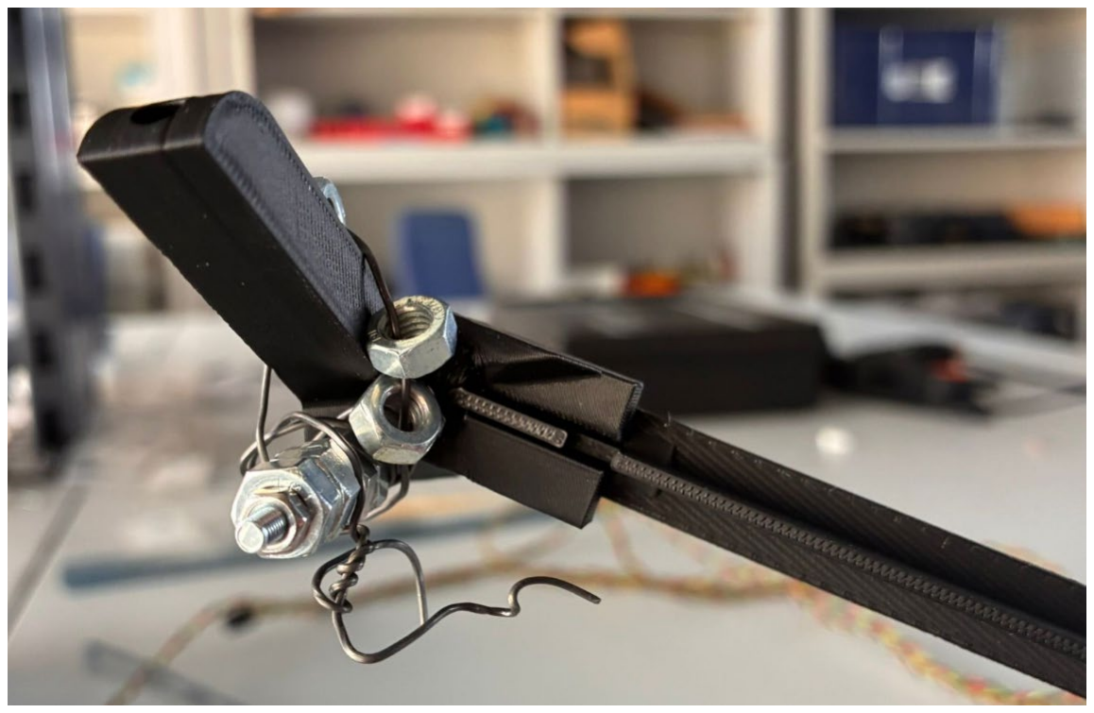
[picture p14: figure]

# Version 1

Arms

- Highly parametric
- Fast to print
- Lightweight
- Strong
- No failure under strong oscillations

# Version 1

Arms

- Highly parametric
- Fast to print
- Lightweight
- Strong
- No failure under strong oscillations
- Mounting the wrong arm
does not have catastrophic results

# Version 1: construction

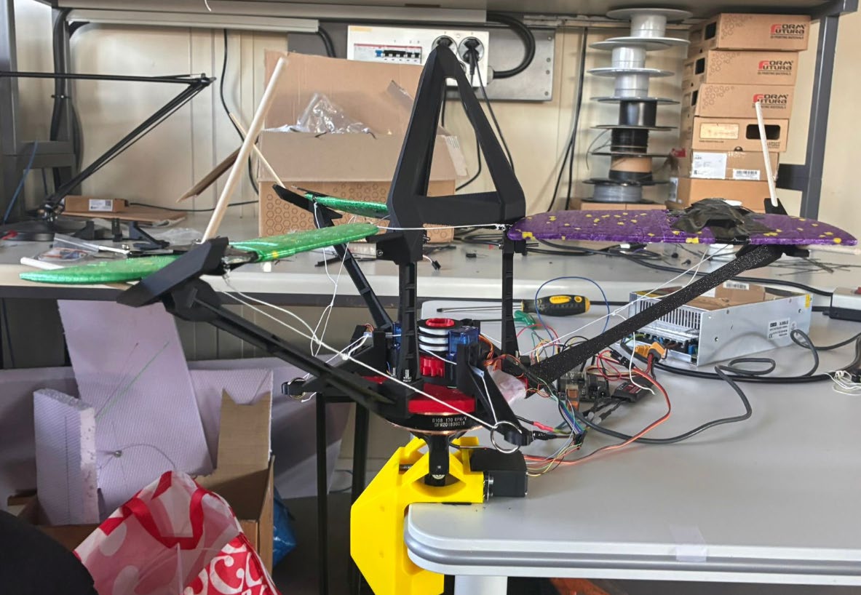
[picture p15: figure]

# Integration: Electronics and software

Before (manual)
Now

# User interface

Projet Image | 35

Quick action

Mimics real operation

Simplifies testing

Repeatable

Real time data

# User interface

Projet Image | 36

Repeatability

Ready for automatic procedures

Modular

Log

Safety (5m cable)

# Testing and results

test

# Testing

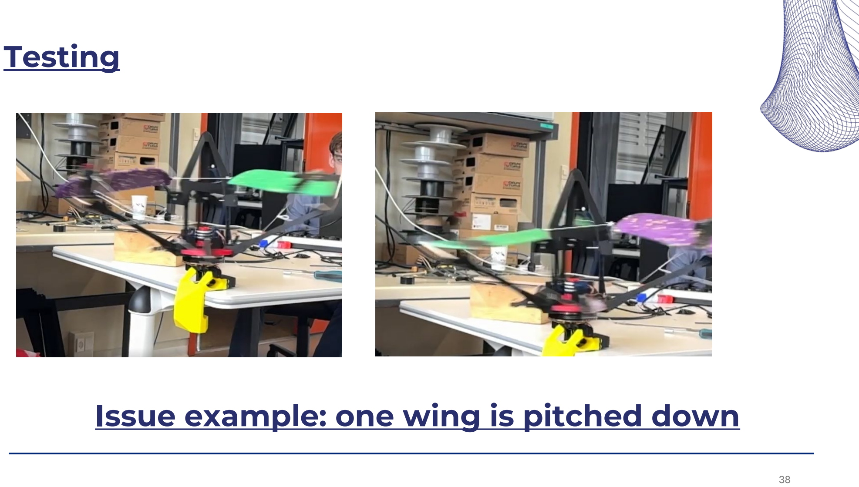
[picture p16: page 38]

# Issue example: one wing is pitched down

# Testing

test | Odd behaviour

# Testing

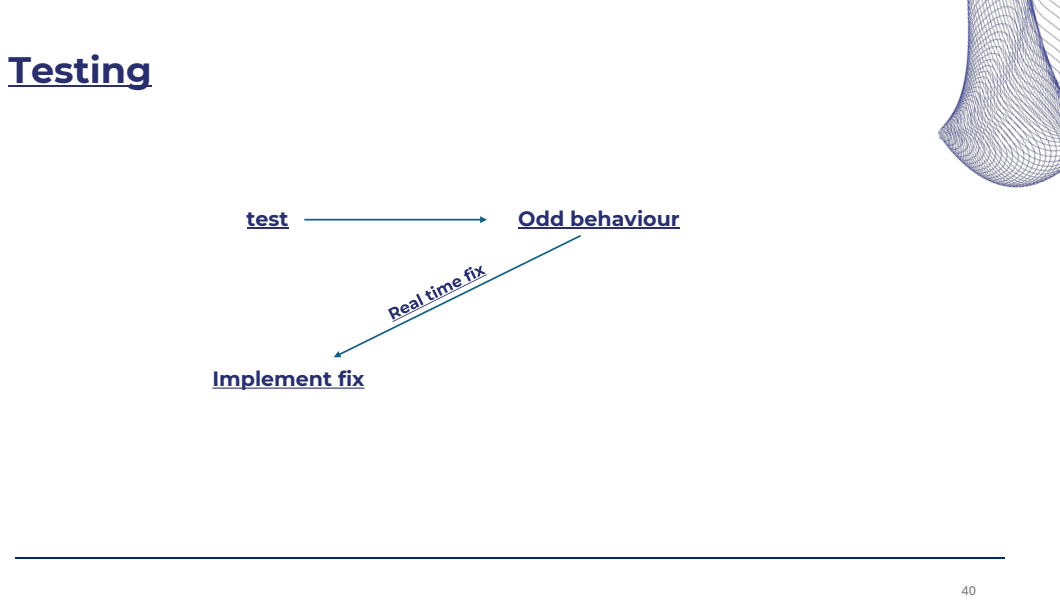
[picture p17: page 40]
test; Odd behaviour; Implement fix

# Testing

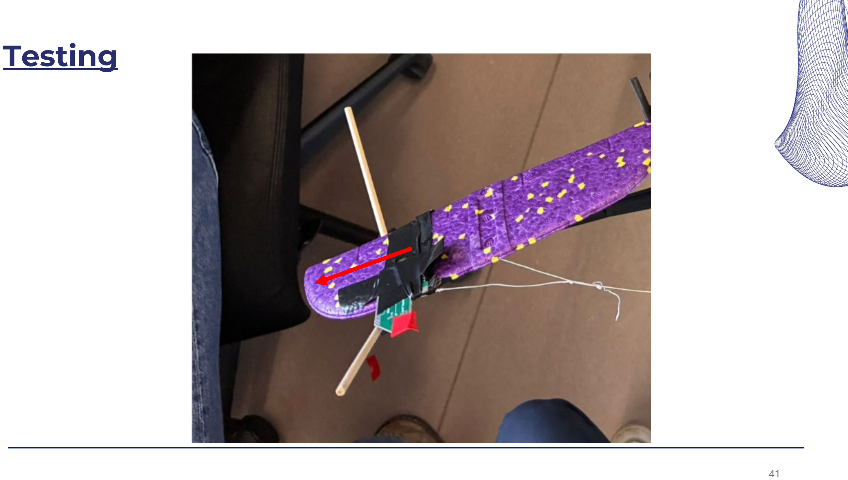
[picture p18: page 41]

# Testing

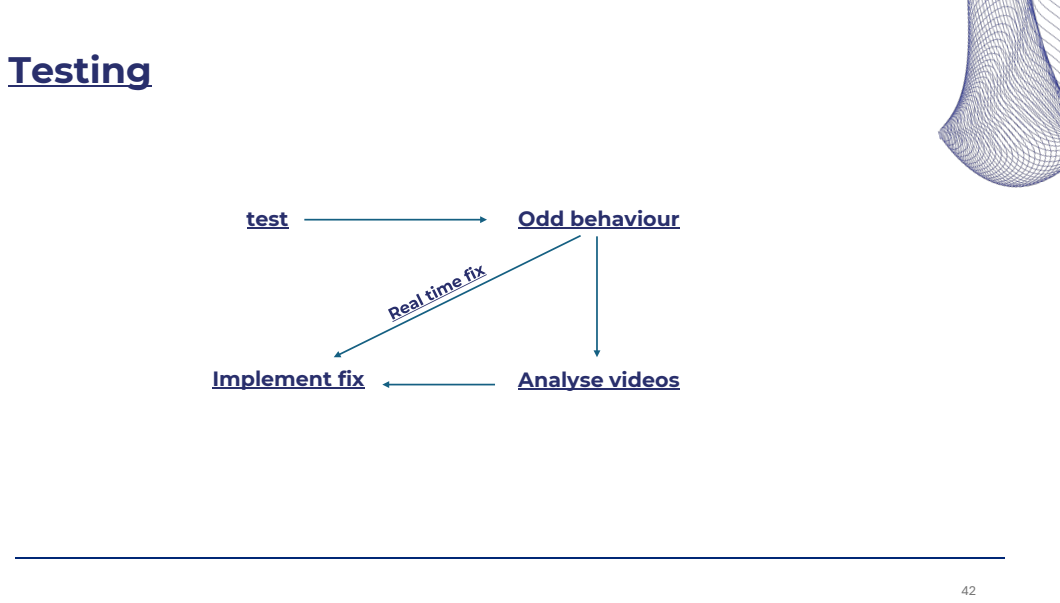
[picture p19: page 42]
test; Odd behaviour; Implement fix; Analyse videos

# Testing

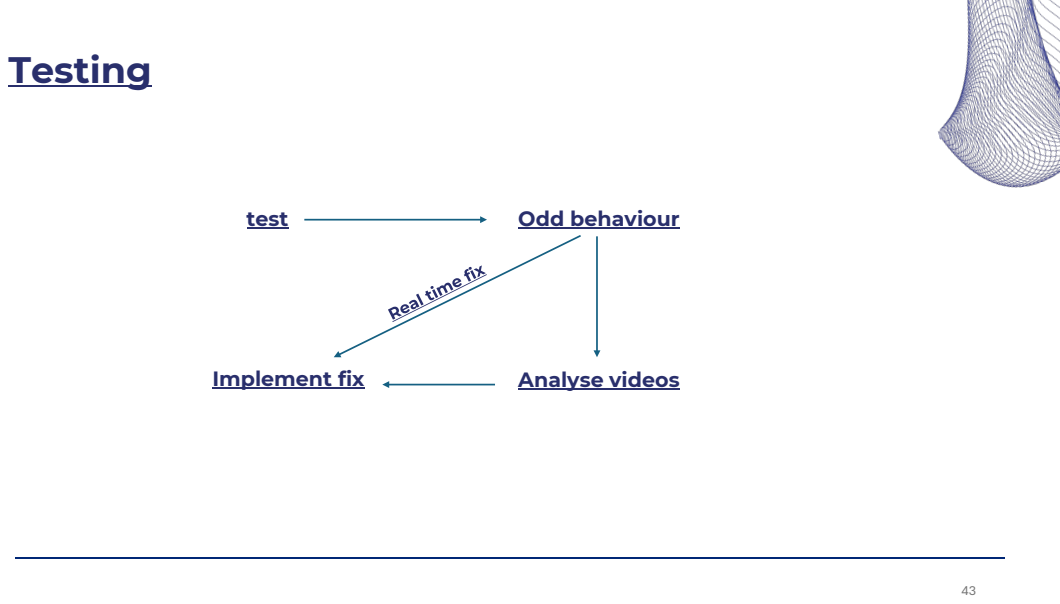
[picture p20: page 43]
test; Odd behaviour; Implement fix; Analyse videos

# Testing

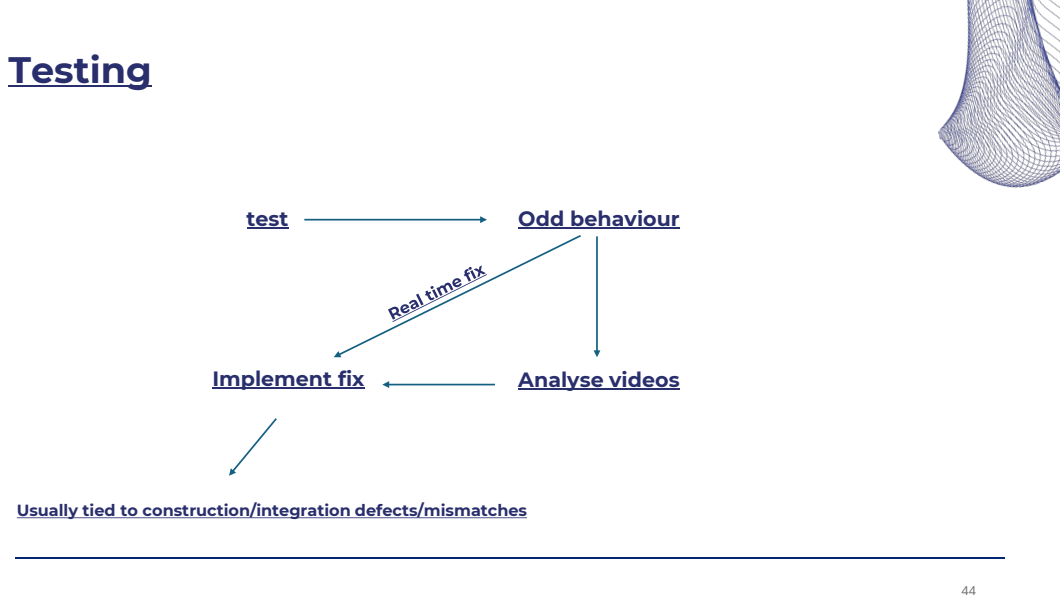
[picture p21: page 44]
test; Odd behaviour; Implement fix; Analyse videos

Usually tied to construction/integration defects/mismatches

# Testing

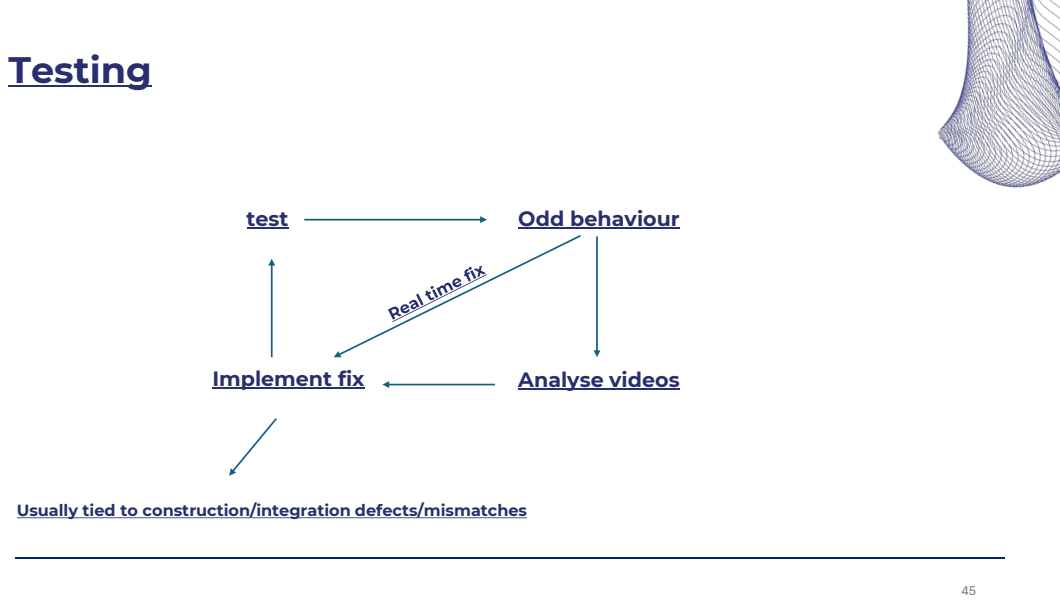
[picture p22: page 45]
test; Odd behaviour; Implement fix; Analyse videos

Usually tied to construction/integration defects/mismatches

# Testing

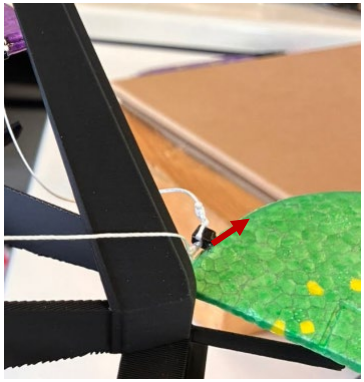
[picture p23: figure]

# Testing

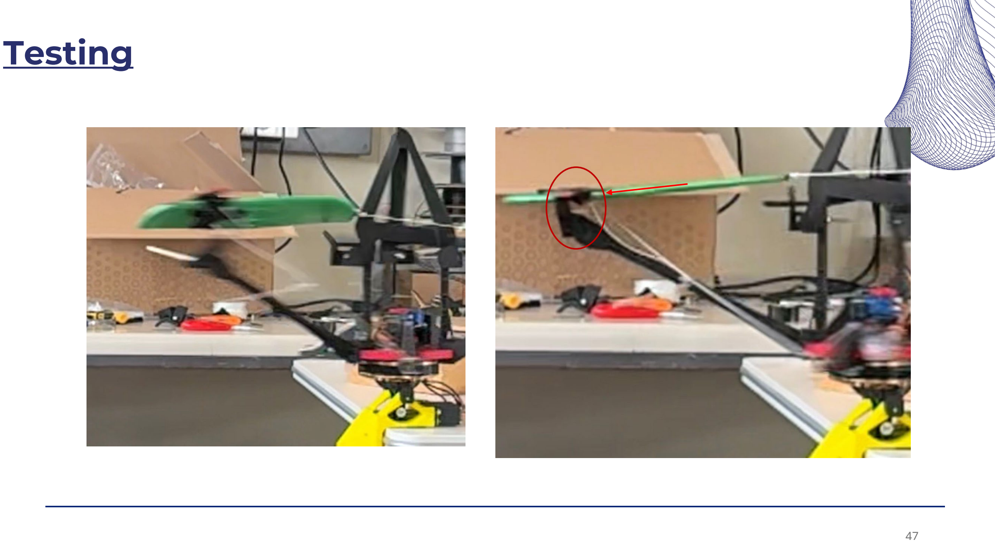
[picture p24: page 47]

# Version 1: shortcomings

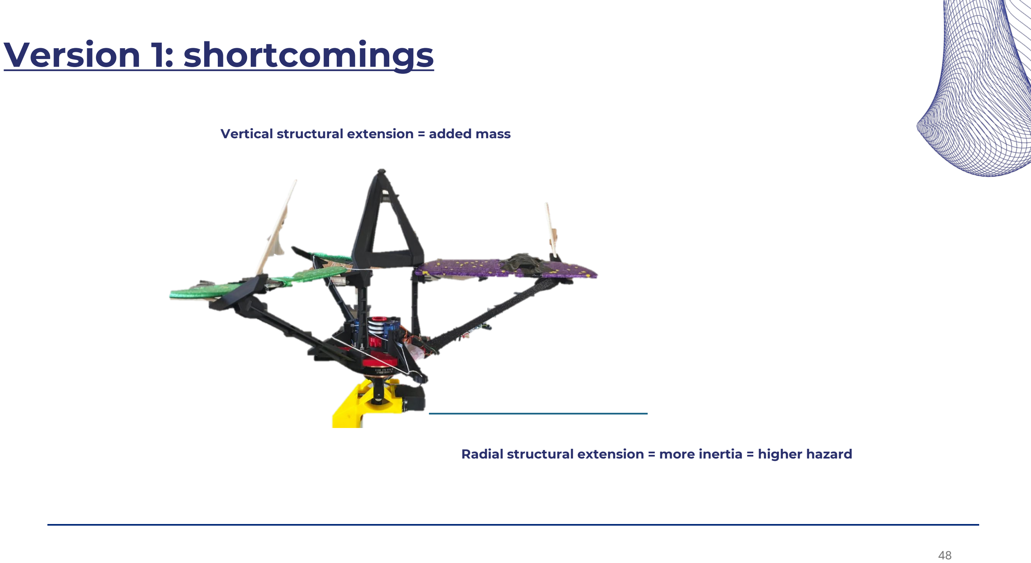
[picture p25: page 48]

Radial structural extension = more inertia = higher hazard

Vertical structural extension = added mass

# Future work

Having a repeatable and clean TOL

Automate the procedure

Improve the current version

# Future version?

hooks

Retractable arm with damping?

Centrifugal force makes it go up

# Future version?

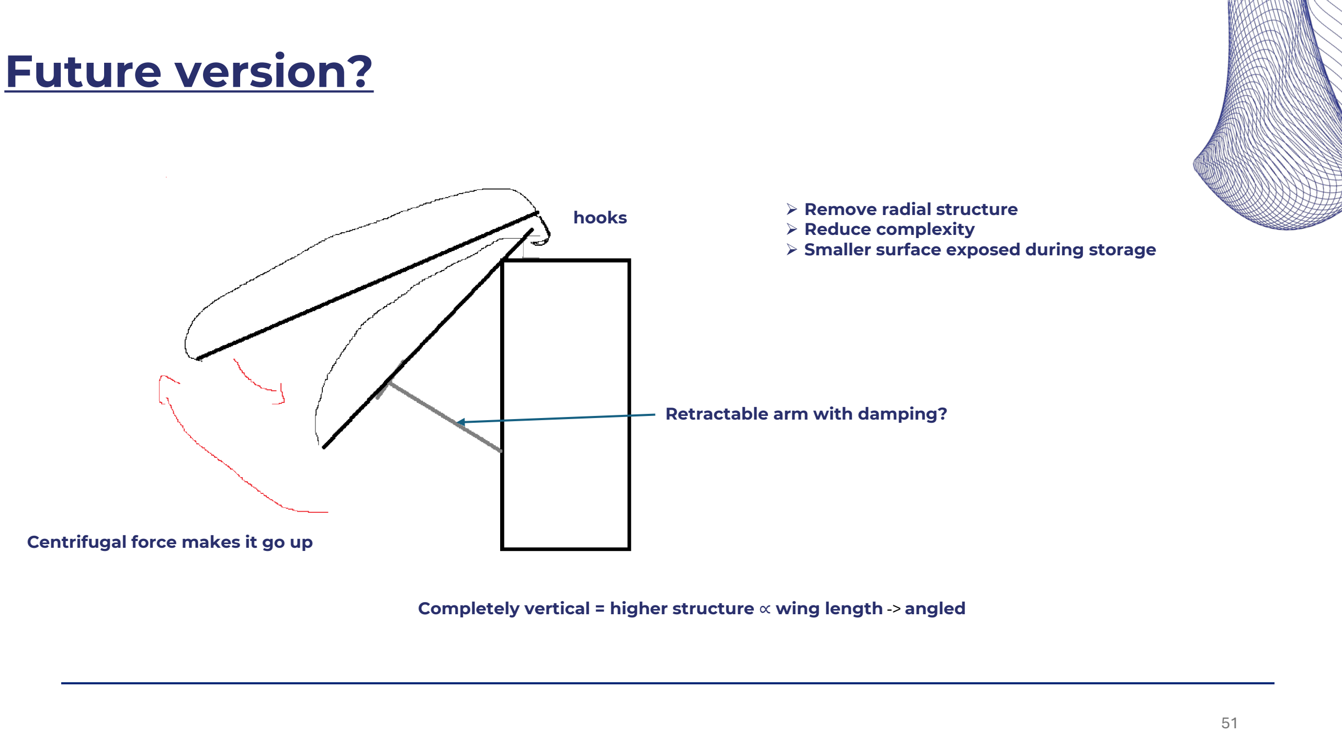
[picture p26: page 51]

hooks

Completely vertical = higher structure ∝ wing length -> angled

Retractable arm with damping?

Centrifugal force makes it go up

- Remove radial structure
- Reduce complexity
- Smaller surface exposed during storage

# Automatic take-off/landing strategies and control for a multi-kite Airborne Wind Energy system

Alex CARRERA | M1 MT
Midterm Presentation

https://site.alphanemo.com/

Supervision: J. Waibel, Prof. C. Jones

# THANK YOU FOR ATTENTION

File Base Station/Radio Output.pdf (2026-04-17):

Radio Output
Item | $LNDAS | Yaw | Pitch | Roll | Xpos | Ypos | Zpos | Latitude | Longitude | Altitude | Thrust | M. Status | Arm. Status | SD Status
Index | 0 | 1 | 2 | 3 | 4 | 5 | 6 | 7 | 8 | 9 | 10 | 11 | 12 | 13
Serial Studio Index | 1 | 2 | 3 | 4 | 5 | 6 | 7 | 8 | 9 | 10 | 11 | 12 | 13 | 14

Radio Output
Item | Target PX | Target PY | Target Altitude | Flight Mode | N. Sat. | RTK Fix Mode | Heading | Gr. Speed | Time UTC | Time Mission | Av. Accuracy | Error message
Index | 14 | 15 | 16 | 17 | 18 | 19 | 20 | 21 | 22 | 23 | 24 | 25
Serial Studio Index | 15 | 16 | 17 | 18 | 19 | 20 | 21 | 22 | 23 | 24 | 25 | 26

ERROR TYPES
ERR- | Value | Comment
Connection Errors [0-9]
NOM | 0 | Nominal
I2C | 1 | I2c Scanner pseudo-checksum (general)
LR1 | 2 | LiDAR connection error
BNO | 3 | BNO055 error
VEC | 4 | Vectornav connection error
TEL | 5 | HC12 error
SRV | 6 | Servo error
BUZ | 7 | Buzzer error

Initial Reading Errors [10-19]

HDN | 10 | Heading errorr
PAN | 11 | Pitch Angle error (>90º)
YAN | 12 | Yaw Angle error (>90º)
LR2 | 13 | Distance >0 or <Xm

Mid Flight Errors [20-29]

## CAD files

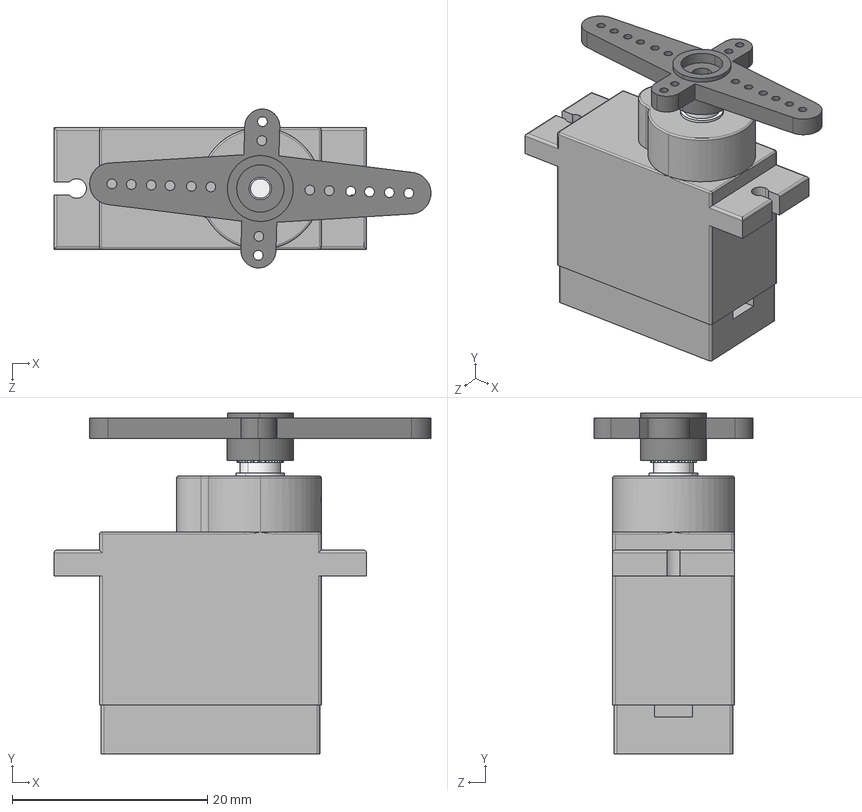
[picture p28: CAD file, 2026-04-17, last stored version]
CAD/mg90-micro-servo-1.snapshot.5/MG90servo_assembly.STEP
38.6 x 34.9 x 16.3 mm
MG90servo_body
MG90servo_shaft
MG90servo_gear

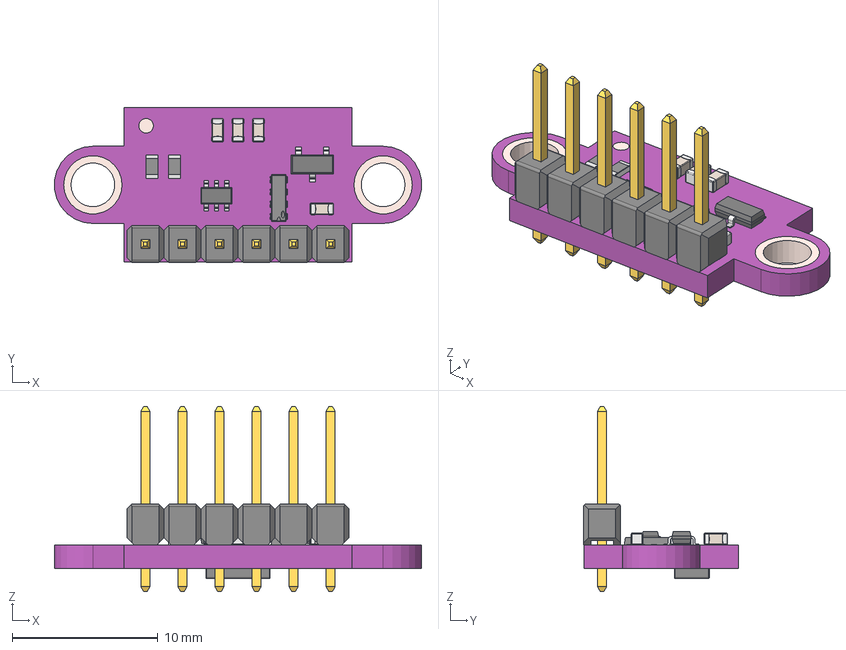
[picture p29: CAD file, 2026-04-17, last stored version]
CAD/vl53l0x-4.snapshot.11/VL53L0X.step
25.2 x 10.6 x 12.7 mm
top
pcb
kork
pads
Document
Document_1
Pin1
Pin2
CeramicBody
Pin1_1
Pin2_1
CeramicBody_1
Pin1_2
Pin2_2
CeramicBody_2
Pin1_3
Pin2_3
CeramicBody_3
SOT-23-3 v1
SOT-23-6 v2
8_Pin_DIP
1x6 TH Pitch 2.54mm v1

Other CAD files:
CAD/Airfoil/Profilé 30cm - Arm.f3d
CAD/mg90-micro-servo-1.snapshot.5/MG90servo_assembly.SLDASM
CAD/vl53l0x-4.snapshot.11/VL53L0X.f3d

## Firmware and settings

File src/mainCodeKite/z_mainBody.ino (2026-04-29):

void setup() {

  Serial.begin(57600);
  initSystem();

}

////////////////////////////////////////////====================SETUP END & MAIN LOOP START====================/////////////////////////////////////////

void loop() {
  checkStateSystem();
  handleTelemetry();

  handleReelServo();
  handleMotor();
  handleBaseTiltServo();
}

////////////////////////////////////////////====================MAIN LOOP END====================/////////////////////////////////////////
